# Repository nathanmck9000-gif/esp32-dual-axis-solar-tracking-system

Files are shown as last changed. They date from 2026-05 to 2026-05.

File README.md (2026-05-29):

# esp32-dual-axis-solar-tracking-system

Project Title: Design, Assembly, and Performance Analysis of a Dual-Axis Sun-Tracking Solar Panel.
Overview

The aim of this project was to develop a prototype dual-axis sun-tracking system for a 1.5W, 6V solar PV panel, and to then
examine said panel’s power output performance compared to a non-tracked solar panel under real weather conditions in Dublin,
Ireland.

Features:
 -Dual-axis solar tracking
 -ESP32 control system
 -LDR-based sunlight detection
 -Servo motor positioning
 -Bluetooth telemetry
 -Power monitoring
 -3D-printed mount

Hardware Used:
 -ESP32
 -Servo motors
 -LDRs
 -Current sensors
 -Solar PV panels

Software Used:
 -Arduino IDE
 -Onshape

## Photo of Dual-Axis Sun-Tracking Mount

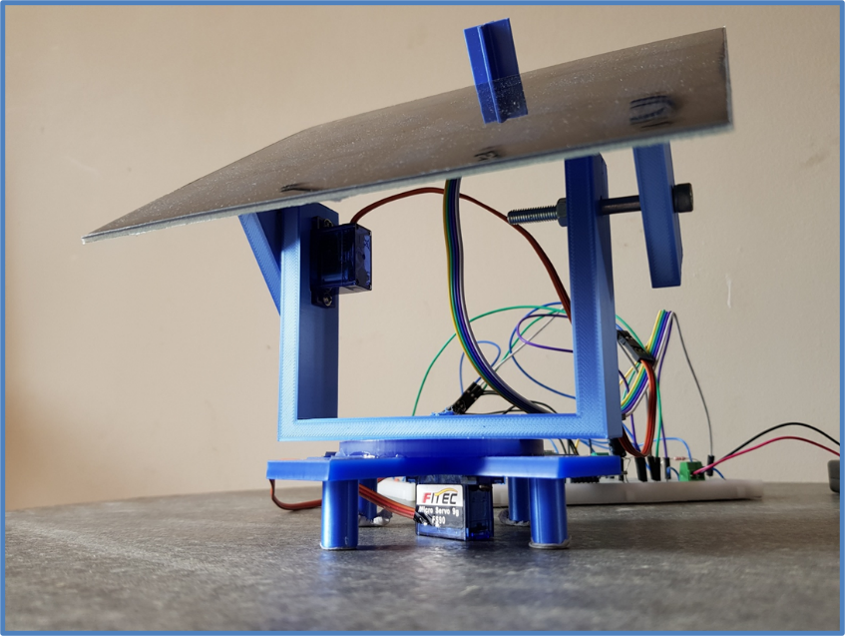
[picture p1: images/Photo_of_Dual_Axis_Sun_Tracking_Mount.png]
Photo of Dual-Axis Tracker


## CAD Design

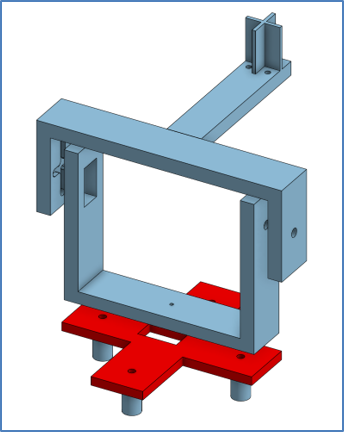
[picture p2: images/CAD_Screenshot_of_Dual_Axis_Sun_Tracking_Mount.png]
CAD Model


## Wiring Diagram

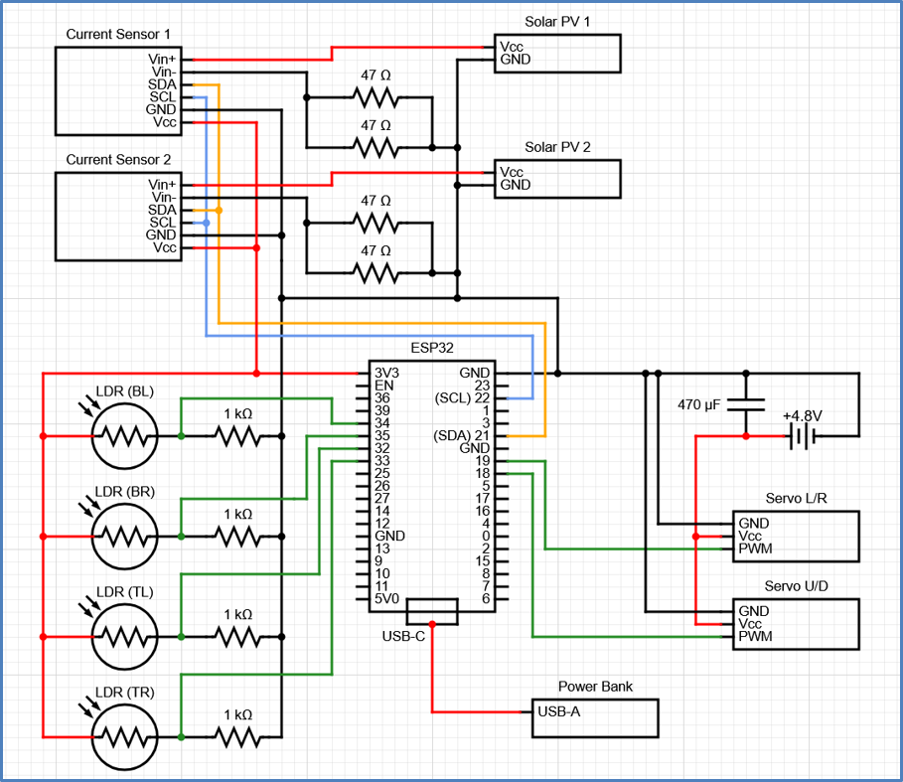
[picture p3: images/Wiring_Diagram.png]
Wiring Diagram


## Graph of Power Output over Time for Dublin City on Thursday 02-Apr-2026

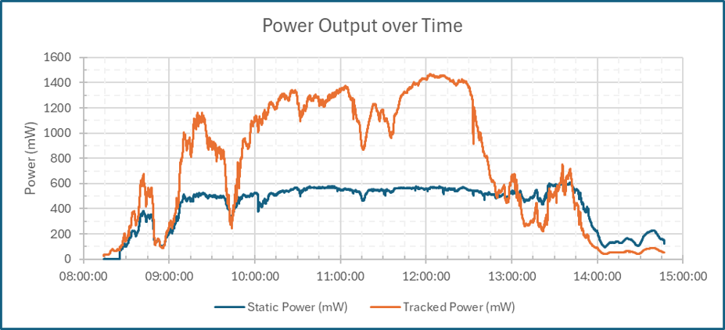
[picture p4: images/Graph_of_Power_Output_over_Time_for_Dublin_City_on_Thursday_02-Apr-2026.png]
Graph of Power Output over Time


## Graph of Dual Axis Tracker Servo Angles VS Sun Location Data for Dublin City on Thursday 02-Apr-2026

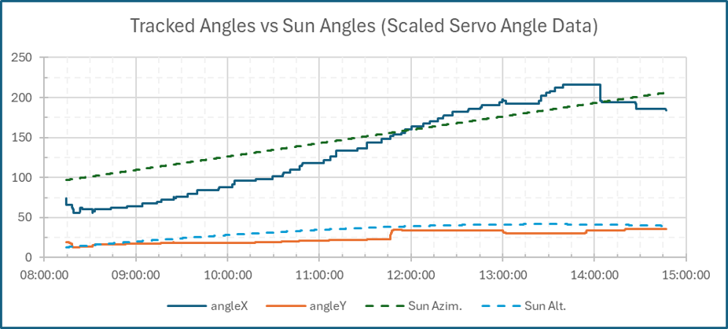
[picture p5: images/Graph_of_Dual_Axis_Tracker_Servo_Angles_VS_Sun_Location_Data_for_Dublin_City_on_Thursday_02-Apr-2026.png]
Graph of Tracker Servo Angles VS Sun Location


Further details regarding this project can be found in the project report.

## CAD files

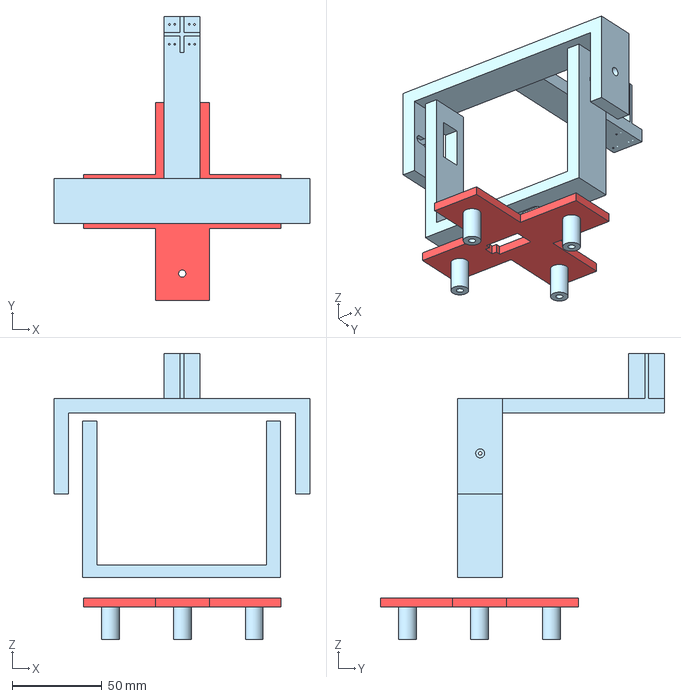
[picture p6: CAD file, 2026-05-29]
cad/Assembly/Dual_Axis_Sun_Tracking_Mount.step
142.0 x 158.0 x 158.9 mm

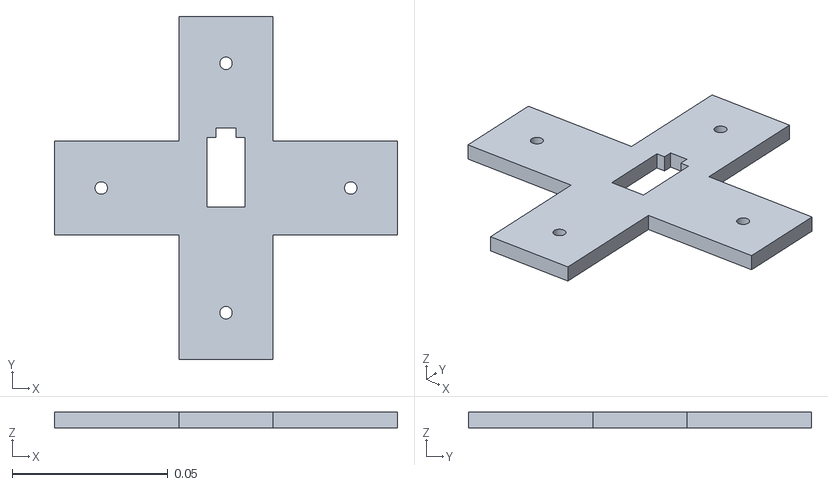
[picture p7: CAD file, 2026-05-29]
cad/stl/Base.stl
0.11 x 0.11 x 0.005

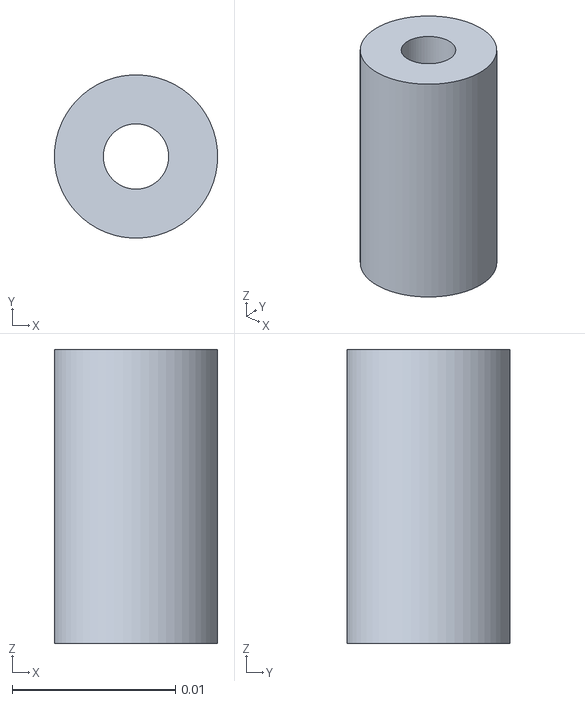
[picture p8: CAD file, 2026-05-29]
cad/stl/Base_Leg.stl
0.01 x 0.00999 x 0.018

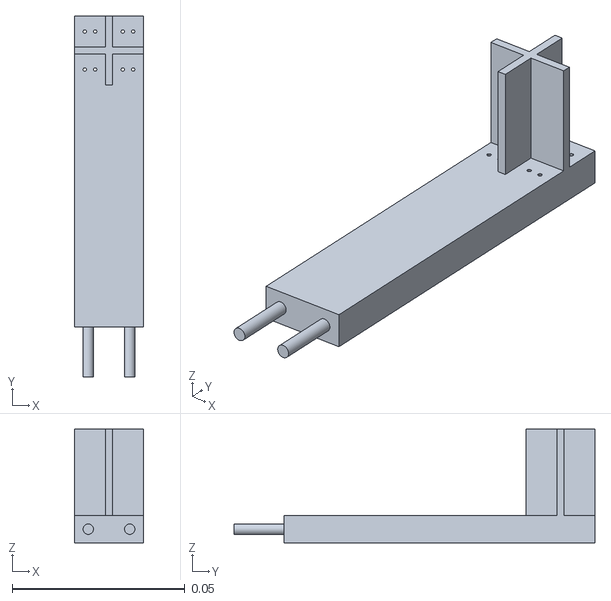
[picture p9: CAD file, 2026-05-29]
cad/stl/LDR_Mount.stl
0.02 x 0.105 x 0.033

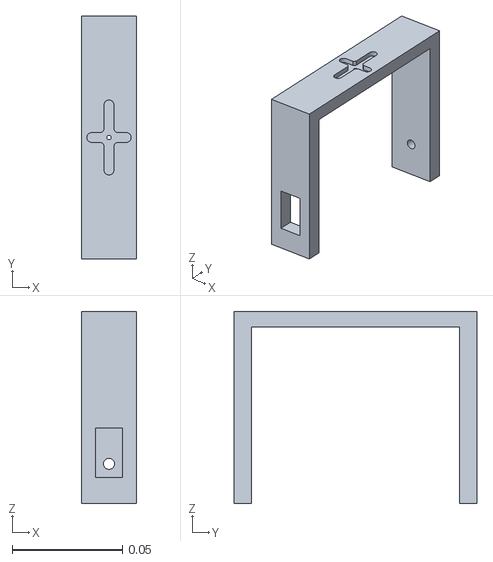
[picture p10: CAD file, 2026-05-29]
cad/stl/Servo_L-R.stl
0.025 x 0.11 x 0.087

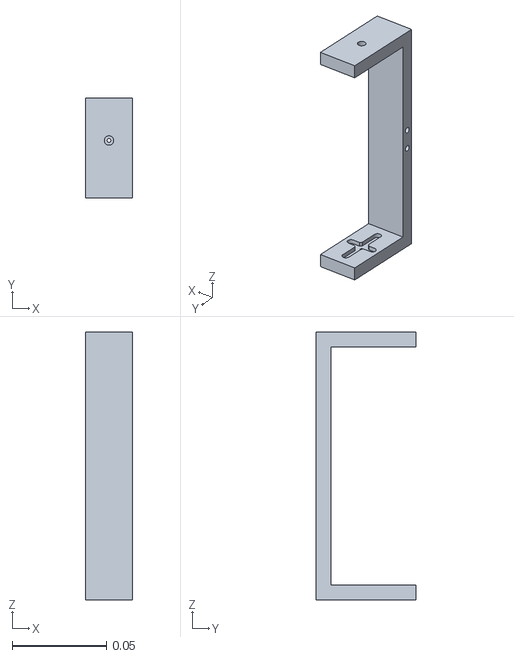
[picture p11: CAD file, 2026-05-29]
cad/stl/Servo_U-D.stl
0.025 x 0.053 x 0.142

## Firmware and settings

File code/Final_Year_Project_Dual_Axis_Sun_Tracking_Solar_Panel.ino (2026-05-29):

/*
Final Year Project for BEng(Hons) in Sustainable Energy and Environmental Engineering.

This code takes in power output data for both a dual-axis sun-tracking solar panel and
a static solar panel simultaneously. 4x LDRs are used to measure the direction of highest
light intensity, and 2x servo motors are used to move the dual-axis solar panel. Data is
transmitted via Bluetooth communication.

Features:
  - Dual-axis sun tracking
  - ESP32 control
  - LDR sensing
  - Servo motor positioning
  - Bluetooth telemetry
  - Power monitoring

Written by Nathan McKee on 02/Apr/2026
*/ 

#include <ESP32Servo.h>        // For Servos
#include <Wire.h>              // Enables I2C Communication
#include <Adafruit_INA219.h>   // For Current Sensors
#include "BluetoothSerial.h"   // For Bluetooth Communication

// Define two INA219 Current Sensors with different addresses
Adafruit_INA219 ina219_1(0x40); // Static Panel (Black Wires)
Adafruit_INA219 ina219_2(0x41); // Tracked Panel (Blue Wires)

// Define Bluetooth
BluetoothSerial SerialBT;

// Analog pins for LDRs
const int ldrTR = 34;
const int ldrBL = 35;
const int ldrBR = 32;
const int ldrTL = 33;

// Variables for average LDR values so that they can be printed for debugging
float topAvg = 0;
float bottomAvg = 0;
float leftAvg = 0;
float rightAvg = 0;

// Variables to hold these values (later printed for debugging)
float diff_LR = 0;
float diff_UD = 0;

// Servo pins
const int servoXPin = 19; // Left & Right
const int servoYPin = 18; // Up & Down

// Define Servos
Servo servoX;
Servo servoY;

// Initial servo angles
int angleX = 90;
int angleY = 90;

// Tuning parameters
const int threshold = 100;  // Sensitivity threshold
const int stepSize  = 1;    // How much to move per adjustment
const int minAngleX = 0;    // Facing towards ServoX wires
const int maxAngleX = 180;  // Facing away from ServoX wires
const int minAngleY = 40;   // Facing downwards (angled)
const int maxAngleY = 150;  // Facing upwards (directly)

// Time intervals for "void loop()"
const unsigned long SERVO_INTERVAL = 250;   // ms
const unsigned long LOG_INTERVAL   = 1000;  // ms
unsigned long lastServoUpdate = 0;
unsigned long lastLogTime = 0;

// Needed for headers to consistently print
bool headerSent = false;

// Values that determine if servos are safe to attach
bool servosEnabled = false;
unsigned long servoEnableTime = 0;

// LDR Values
int TL_val = 0;
int TR_val = 0;
int BL_val = 0;
int BR_val = 0;

void setup() {

  Serial.begin(115200);

  // Bluetooth Connection Troubleshoot
  if (!SerialBT.begin("ESP32_Solar")) {
    Serial.println("Bluetooth failed to start!");
  } else {
    Serial.println("Bluetooth started. Device is discoverable.");
  }

  // Let ESP32 connect to PuTTY
  delay(2000);

  // Initialise INA219 Current Sensors + Debugging Messages
  if (!ina219_1.begin()) {
  Serial.println("INA219_1 not found");
  }
  if (!ina219_2.begin()) {
  Serial.println("INA219_2 not found");
  }

  // Calibrate Current Sensors
  ina219_1.setCalibration_16V_400mA();
  ina219_2.setCalibration_16V_400mA();

  // Keep servo pins OFF until they're ready (filters noise)
  pinMode(servoXPin, OUTPUT);
  pinMode(servoYPin, OUTPUT);
  digitalWrite(servoXPin, LOW);
  digitalWrite(servoYPin, LOW);

  // Servos are enabled 3 seconds after they attach
  servoEnableTime = millis() + 3000;
}

void loop() {
  unsigned long current_time = millis();
  
  // IF the servos are NOT enabled yet
  // AND the current time is later than the safety time
  // THEN do the servo setup
  if (!servosEnabled && current_time > servoEnableTime) {
  servoY.attach(servoYPin);
  delay(500);
  servoX.attach(servoXPin);

  // Initialise servo angles
  // Delays to avoid current spikes
  servoY.write(angleY);
  delay(250);
  servoX.write(angleX);
  delay(250);
  
  // servos are now active so don’t run this part again
  servosEnabled = true;
  }
  
  // Table Headings Print Only When Connected to Laptop
  if (SerialBT.hasClient() && !headerSent) {
    SerialBT.println("Measuring voltage and current with INA219 ...");
    SerialBT.println(",Static Panel,,,,,Tracked Panel");
    SerialBT.println("Time (s),Bus Voltage (V),Shunt Voltage (mV),Load Voltage (V),Current (mA),Power (mW),Bus Voltage (V),Shunt Voltage (mV),Load Voltage (V),Current (mA),Power (mW),angleX,angleY,ldrTL,ldrTR,ldrBL,ldrBR,diff_LR,diff_UD");
    headerSent = true;
  }

  // ===== SERVO CONTROL =====
  if (current_time - lastServoUpdate >= SERVO_INTERVAL) {
  lastServoUpdate = current_time;
  
  // Read LDRs
  TL_val = analogRead(ldrTL);
  TR_val = analogRead(ldrTR);
  BL_val = analogRead(ldrBL);
  BR_val = analogRead(ldrBR);

  // Calculate LDR cardinal direction averages
  topAvg = (TL_val + TR_val) / 2;
  bottomAvg = (BL_val + BR_val) / 2;
  leftAvg = (TL_val + BL_val) / 2;
  rightAvg = (TR_val + BR_val) / 2;

  // Values to print for debugging
  diff_LR = abs(leftAvg - rightAvg);
  diff_UD = abs(topAvg - bottomAvg);

  // Vertical adjustment (Servo Y)
  if (abs(topAvg - bottomAvg) > threshold) {
    if (topAvg > bottomAvg) {
      angleY = constrain(angleY + stepSize, minAngleY, maxAngleY);
    } else {
      angleY = constrain(angleY - stepSize, minAngleY, maxAngleY);
    }
    servoY.write(angleY);
  }

  // Horizontal adjustment (Servo X)
  if (abs(leftAvg - rightAvg) > threshold) {
    if (leftAvg > rightAvg) {
      angleX = constrain(angleX + stepSize, minAngleX, maxAngleX);
    } else {
      angleX = constrain(angleX - stepSize, minAngleX, maxAngleX);
    }
    servoX.write(angleX);
  }
  }
  // ===== SERVO CONTROL (END) =====

  // ===== DATA LOGGING =====
  if (current_time - lastLogTime >= LOG_INTERVAL) {
  lastLogTime = current_time;
  
  // Values for Static Panel
  float shuntvoltage_1 = ina219_1.getShuntVoltage_mV();
  float busvoltage_1 = ina219_1.getBusVoltage_V();
  float current_mA_1 = ina219_1.getCurrent_mA();
  float power_mW_1 = ina219_1.getPower_mW();
  float loadvoltage_1 = busvoltage_1 + (shuntvoltage_1 / 1000);

  // Values for Tracked Panel
  float shuntvoltage_2 = ina219_2.getShuntVoltage_mV();
  float busvoltage_2 = ina219_2.getBusVoltage_V();
  float current_mA_2 = ina219_2.getCurrent_mA();
  float power_mW_2 = ina219_2.getPower_mW();
  float loadvoltage_2 = busvoltage_2 + (shuntvoltage_2 / 1000);

  float time_s = current_time / 1000;

  // Smooth out noise so graphs look cleaner (Keep an eye on this)
  if (abs(current_mA_1) < 0.2) current_mA_1 = 0;
  if (busvoltage_1 < 0.01) busvoltage_1 = 0;

  if (abs(current_mA_2) < 0.2) current_mA_2 = 0;
  if (busvoltage_2 < 0.01) busvoltage_2 = 0;
  
  // Print Values to PuTTY
  SerialBT.printf(
    "%.2f,%.3f,%.3f,%.3f,%.3f,%.3f,%.3f,%.3f,%.3f,%.3f,%.3f,%d,%d,%d,%d,%d,%d,%.3f,%.3f\r\n",
    time_s,
    busvoltage_1,
    shuntvoltage_1,
    loadvoltage_1,
    current_mA_1,
    power_mW_1,
    busvoltage_2,
    shuntvoltage_2,
    loadvoltage_2,
    current_mA_2,
    power_mW_2,
    angleX,
    angleY,
    TL_val,         // LDR Values for Debugging
    TR_val,         // LDR Values for Debugging
    BL_val,         // LDR Values for Debugging
    BR_val,         // LDR Values for Debugging
    diff_LR,        // LDR Diff Values for Debugging
    diff_UD         // LDR Diff Values for Debugging
  );
  }
    // ===== DATA LOGGING (END) =====
}
